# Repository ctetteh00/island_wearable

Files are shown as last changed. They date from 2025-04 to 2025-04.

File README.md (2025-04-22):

# 🌡️ Heat Risk Monitoring System

A dual-device system for real-time, personalized heat stress monitoring. Combines ESP32-based wearable and stationary nodes with a Firebase-connected dashboard to calculate the Modified Physiological Strain Index (mPSI), Heat Index, and a user-specific risk score.

## 🚀 Project Structure

- **Stationary Device**: Measures ambient temperature and humidity, broadcasts data via ESP-NOW.
- **Wearable Device**: Receives strongest signal, calculates skin temperature, uploads all data to Firebase.
- **Web Dashboard**: Real-time interface for monitoring risk levels and metrics.

---

## Repository Structure
/island_wearable/
├── firmware/
│   ├── wearable.ino         # Wearable ESP32 firmware
│   ├── stationary.ino       # Stationary ESP32 firmware
│   └── secrets.h            # Credentials (use from .env)
├── public/
│   ├── index.html           # Web UI
│   ├── app.js               # Logic & Firebase JS SDK
├── docs/
│   ├── 462_island_wearable_2.zip
    ├── wearable.kicad_pcb
    ├── wearable.kicad_pro
    ├── wearable.kicad_sch 
    ├── wearable_circuit_schematic.png
    ├── wearable_pcb_schematic.png
│   └── stationary_schematic.png
├── .env                     # Environment variables
├── setup_dependencies.sh # Library Dependencies for Arduino
├── README.md

## 📦 Hardware Components

### Wearable Device

| Component | Part Number | Description |
|---|---|---|
| Microcontroller | Arduino Nano ESP32 | Wi-Fi + ESP-NOW |
| Temperature Sensor  | TMP236 | Skin temperature measurement |
| Charging Module | Adafruit PowerBoost 1000C | LiPo charging circuit |
| Battery | LP103454 | 3.7V 1000mAh LiPo |
| Strap & Enclosure | Chest band + PLA case  | Wearability and housing |

### Stationary Device

| Component | Part Number | Description |
|---|---|---|
| Microcontroller | Arduino Nano ESP32 | ESP-NOW broadcaster |
| Sensor | DHT22 | Temp + Humidity measurement |
| Power | 9V Battery + Switch | Portable outdoor deployment |
| Case | Acrylic Enclosure | Ventilated weather housing |

---

## 🧠 Features

- ESP-NOW peer-to-peer communication
- RSSI-based device proximity selection
- mPSI calculation with exponential calibration
- Firebase-hosted real-time database
- Personalized scoring with comorbidities, sleep, and medications
- Dynamic UI with recommendations and color-coded feedback

---

## 🌐 Firebase Setup Instructions

1. **Create a Firebase Project**
   - Go to [Firebase Console](https://console.firebase.google.com/)
   - Click **Add Project** → Give it a name → Continue
   - Disable Google Analytics (optional)

2. **Add Realtime Database**
   - Navigate to `Build > Realtime Database`
   - Create a new database in test mode (can secure later)

3. **Set Up Web App**
   - Click **</>** to register a new Web App in Firebase
   - Save the API Key and Database URL (add to `.env`)

4. **Enable Authentication (Optional)**
   - Go to `Authentication > Sign-in method`
   - Enable "Email/Password" or other methods

---

## 🔒 Environment Configuration

Add a `.env` file in the root of your repo:

```env
# Firebase Credentials
FIREBASE_API_KEY=your_api_key_here
FIREBASE_DATABASE_URL=https://your-database-name.firebaseio.com

# WiFi Access
WIFI_SSID="YourNetwork"
WIFI_PASSWORD="YourPassword"

# Optional
WIFI_CHANNEL=1

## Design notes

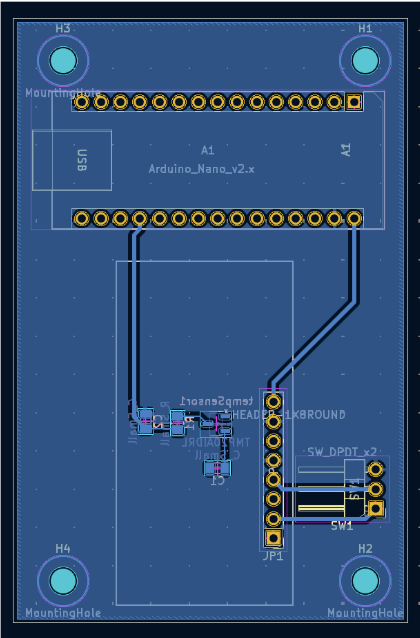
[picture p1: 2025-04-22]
docs/wearable_pcb_schematic.png

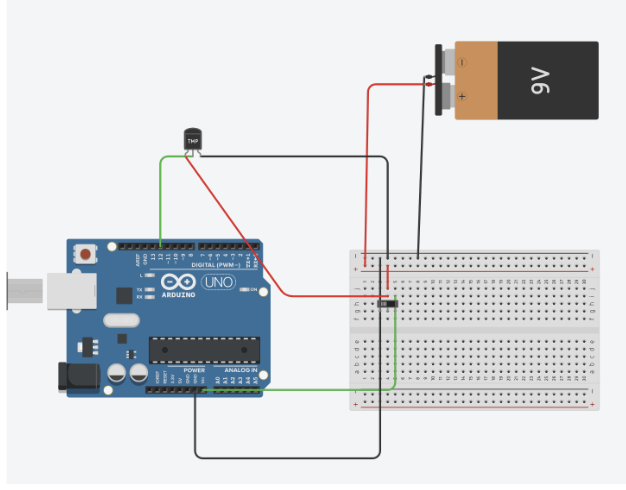
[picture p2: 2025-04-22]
docs/stationary_schematic.png

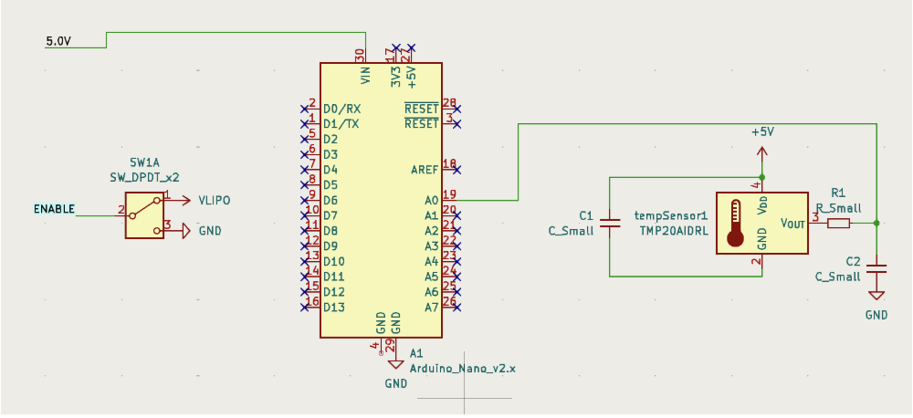
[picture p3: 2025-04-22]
docs/wearable_circuit_schematic.png

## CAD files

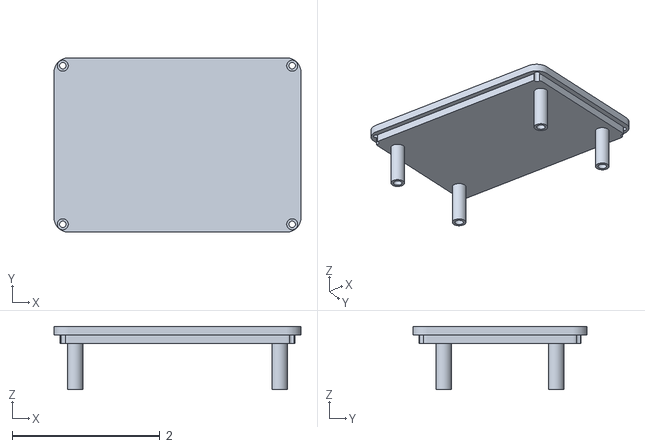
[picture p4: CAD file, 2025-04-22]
stl/Wearable V3 - 2.stl
3.35 x 2.36 x 0.859

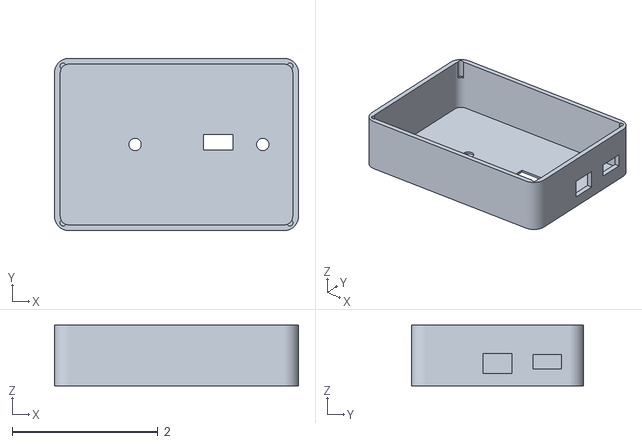
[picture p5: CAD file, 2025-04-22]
stl/Wearable V3-1.stl
3.35 x 2.36 x 0.831

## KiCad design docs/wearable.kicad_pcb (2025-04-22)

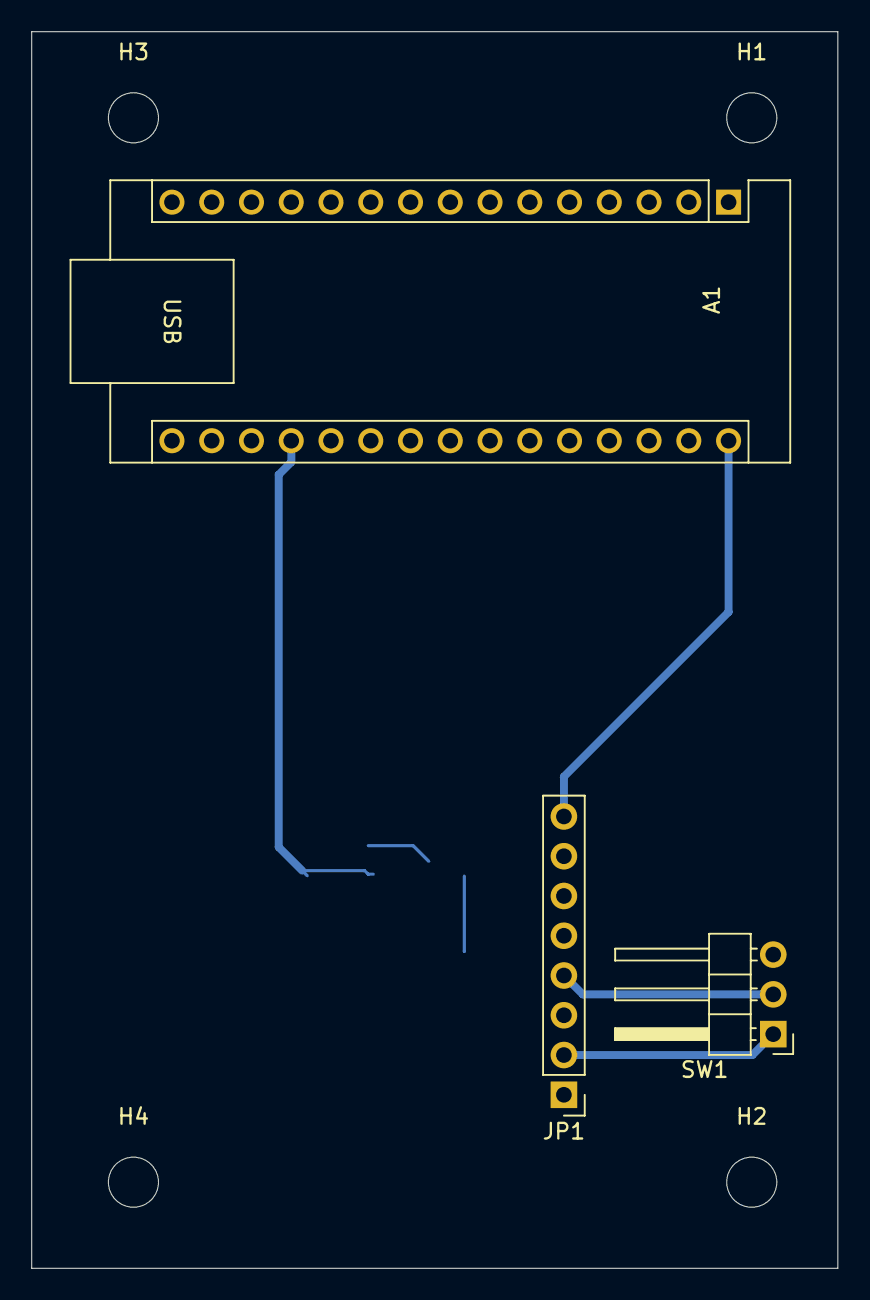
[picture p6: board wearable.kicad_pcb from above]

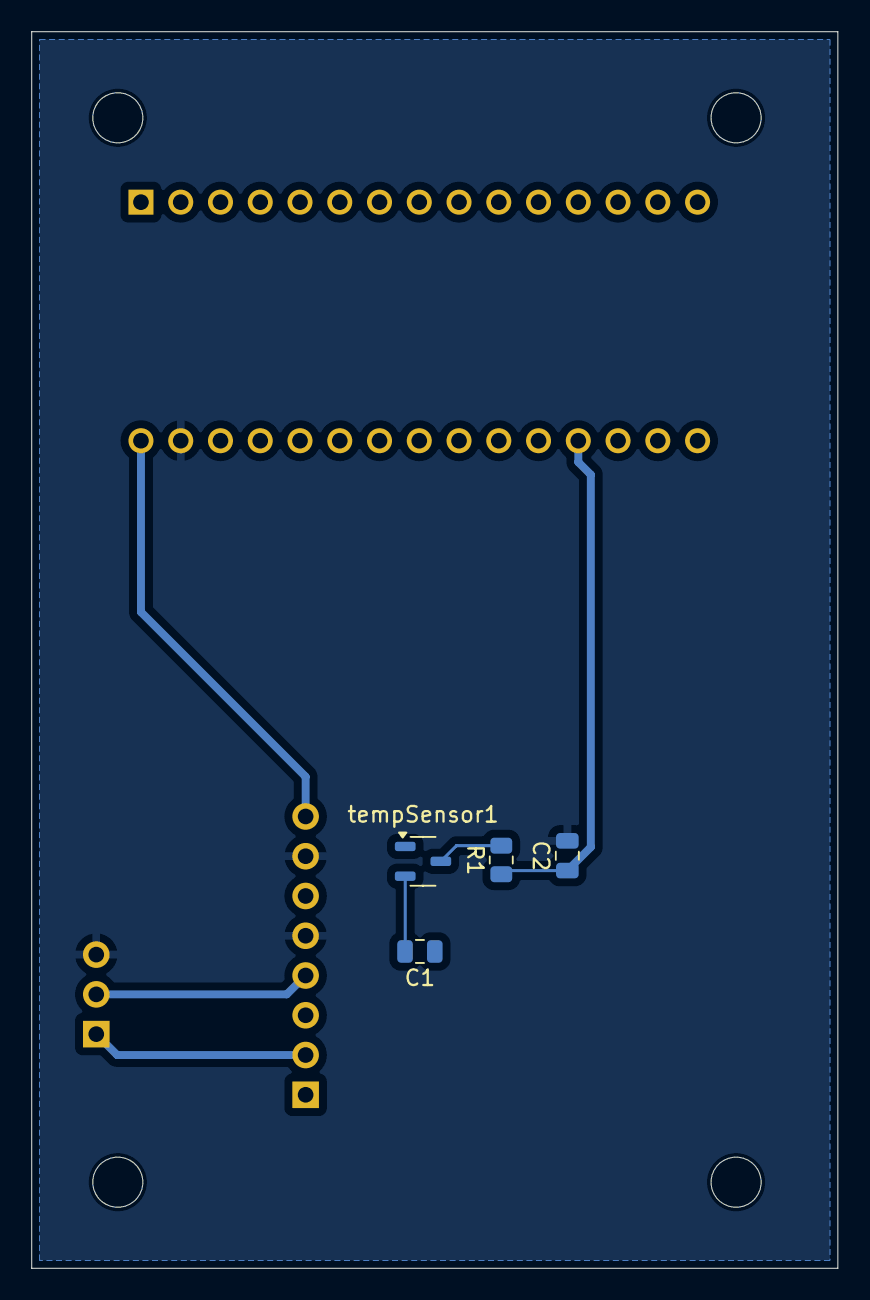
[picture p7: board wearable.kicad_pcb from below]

Board: 2 copper layers, 51.5 x 79.0 mm, 11 parts (4 on the bottom side), 7 nets.

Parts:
A1: Arduino_Nano_v2.x; Arduino_Nano
C1, C2: C_Small; C_0805_2012Metric
H1, H2, H3, H4: MountingHole; MountingHole_3.2mm_M3
JP1: HEADER-1X8ROUND; PinHeader_1x08_P2.54mm_Vertical
R1: R_Small; R_0805_2012Metric
SW1: SW_DPDT_x2; PinHeader_1x03_P2.54mm_Horizontal
tempSensor1: TMP20AIDRL; SOT-23-3

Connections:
5.0V: A1.30 (VIN), JP1.8
/ENABLE: JP1.4, SW1.2 (B)
GND: A1.29 (GND), C2.2, JP1.5, JP1.7, SW1.3 (C)
unnamed: A1.19 (A0), C2.1, R1.1
unnamed: C1.2, tempSensor1.2 (GND)
unnamed: R1.2, tempSensor1.3 (V_{OUT})
VLIPO: JP1.2, SW1.1 (A)

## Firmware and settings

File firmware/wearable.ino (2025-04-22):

// ----------------------------------------
// Heat Risk Monitoring - Wearable Node
// ESP32 Wearable Node receives ESP-NOW data and uploads to Firebase
// ----------------------------------------

#include <Arduino.h>
#include <WiFi.h>
#include <Firebase_ESP_Client.h>
#include <esp_now.h>
#include <esp_wifi.h>
#include <vector>
#include <algorithm>
#include "secrets.h"

// Firebase Helper Includes
#include "addons/TokenHelper.h"
#include "addons/RTDBHelper.h"

// Firebase objects
FirebaseData fbdo;
FirebaseAuth auth;
FirebaseConfig config;
FirebaseJson json;

// Firebase data paths
const char* tempSPath = "/skintemp";
const char* tempAPath = "/ambtemp";
const char* humPath   = "/humidity";
const char* parentPath = "sensor_data";

// Timing
unsigned long sendDataPrevMillis = 0;
const unsigned long sensorTimeout = 10000;
bool signupOK = false;

// -------------------------------
// ESP-NOW Data Structure
// -------------------------------
typedef struct struct_sensor_data {
  uint8_t macAddr[6];
  float skin_temperature;
  float ambient_temperature;
  float humidity;
} sensor_data;

typedef struct received_data_t {
  uint8_t macAddr[6];
  float skin_temperature;
  float ambient_temperature;
  float humidity;
  int8_t rssi;
  unsigned long lastSeen;
} received_data_t;

std::vector<received_data_t> nearbySensors;

// -------------------------------
// Temperature Sensor Setup
// -------------------------------
const int TempPin = 18; // Analog pin connected to TMP236 white wire
const int BUFFER_SIZE = 6;
float temp[BUFFER_SIZE];
int count = 0;
float Vout = 0;

// -------------------------------
// Utility Function: Check MAC Equality
// -------------------------------
bool isSameMac(const uint8_t *addr1, const uint8_t *addr2) {
  return memcmp(addr1, addr2, 6) == 0;
}

// -------------------------------
// ESP-NOW Receive Callback
// -------------------------------
void OnDataRecv(const esp_now_recv_info_t *recv_info, const uint8_t *incomingData, int len) {
  Serial.println("ESP-NOW data received!");
  const uint8_t *peer_addr = recv_info->src_addr;

  if (len == sizeof(sensor_data)) {
    sensor_data receivedTempData;
    memcpy(&receivedTempData, incomingData, sizeof(receivedTempData));
    int8_t rssi = recv_info->rx_ctrl->rssi;

    bool found = false;
    for (auto &sensor : nearbySensors) {
      if (isSameMac(sensor.macAddr, peer_addr)) {
        sensor.skin_temperature = getSkinTemp();
        sensor.ambient_temperature = receivedTempData.ambient_temperature;
        sensor.humidity = receivedTempData.humidity;
        sensor.rssi = rssi;
        sensor.lastSeen = millis();
        found = true;
        break;
      }
    }

    if (!found) {
      received_data_t newSensor;
      memcpy(newSensor.macAddr, peer_addr, 6);
      newSensor.skin_temperature = getSkinTemp();
      newSensor.ambient_temperature = receivedTempData.ambient_temperature;
      newSensor.humidity = receivedTempData.humidity;
      newSensor.rssi = rssi;
      newSensor.lastSeen = millis();
      nearbySensors.push_back(newSensor);
      Serial.print("New sensor discovered with MAC: ");
      for (int i = 0; i < 6; i++) Serial.printf("%02X:", peer_addr[i]);
      Serial.println();
    }

    Serial.printf("Ambient Temp: %.2f°F, RSSI: %d\n", receivedTempData.ambient_temperature, rssi);
  } else {
    Serial.println("ESP-NOW data length mismatch!");
  }
}

// -------------------------------
// Utility Function: Find Nearest Sensor
// -------------------------------
received_data_t* findNearestSensor() {
  if (nearbySensors.empty()) return nullptr;
  received_data_t* nearest = &nearbySensors[0];
  for (size_t i = 1; i < nearbySensors.size(); ++i) {
    if (nearbySensors[i].rssi > nearest->rssi) {
      nearest = &nearbySensors[i];
    }
  }
  return nearest;
}

// -------------------------------
// Setup Function
// -------------------------------
void setup() {
  Serial.begin(115200);
  analogReadResolution(10);
  pinMode(TempPin, INPUT);

  WiFi.mode(WIFI_STA);
  Serial.println("Wearable MAC Address: " + WiFi.macAddress());

  esp_wifi_set_channel(1, WIFI_SECOND_CHAN_NONE);

  if (esp_now_init() == ESP_OK) {
    Serial.println("ESP-NOW initialized");
    esp_now_register_recv_cb(OnDataRecv);
  } else {
    Serial.println("ESP-NOW init failed");
    return;
  }

  // Wi-Fi for Firebase (use empty password for DukeOpen)
  WiFi.begin(WIFI_SSID, "", 1);
  Serial.print("Connecting to Wi-Fi");
  while (WiFi.status() != WL_CONNECTED) {
    Serial.print(".");
    delay(300);
  }
  Serial.println("Connected to WiFi");

  // Firebase setup
  config.api_key = API_KEY;
  config.database_url = DATABASE_URL;
  config.token_status_callback = tokenStatusCallback;

  if (Firebase.signUp(&config, &auth, "", "")) {
    Serial.println("Firebase sign-up OK");
    signupOK = true;
  } else {
    Serial.printf("Firebase sign-up failed: %s\n", config.signer.signupError.message.c_str());
  }

  Firebase.begin(&config, &auth);
  Firebase.reconnectWiFi(true);
}

// -------------------------------
// Measure Skin Temperature
// -------------------------------
float getSkinTemp() {
  Vout = (((float)analogRead(TempPin) * 3.3) / 4095.0) * 1000; // Convert to mV
  float celsiusExpCal = 7.3975 * exp(0.0014 * Vout);
  float celsiusPolyCal = 0.00005 * Vout * Vout + 0.0037 * Vout + 6.09;
  float celsiusAvg = ((celsiusExpCal + celsiusPolyCal) / 2) + 12;
  Serial.printf("Calculated Skin Temp: %.2f °C\n", celsiusAvg);
  return celsiusAvg;
}

// -------------------------------
// Main Loop
// -------------------------------
void loop() {
  // Remove sensors not heard from in a while
  nearbySensors.erase(std::remove_if(nearbySensors.begin(), nearbySensors.end(),
    [](const received_data_t& s) { return (millis() - s.lastSeen > sensorTimeout); }),
    nearbySensors.end());

  received_data_t* nearestSensorPtr = findNearestSensor();

  if (signupOK && nearestSensorPtr != nullptr && (millis() - sendDataPrevMillis > 15000)) {
    sendDataPrevMillis = millis();

    Serial.println("Uploading to Firebase from nearest sensor:");
    for (int i = 0; i < 6; i++) Serial.printf("%02X:", nearestSensorPtr->macAddr[i]);
    Serial.println();
    Serial.printf("Skin Temp: %.2f °C\n", nearestSensorPtr->skin_temperature);
    Serial.printf("Ambient Temp: %.2f °F\n", nearestSensorPtr->ambient_temperature);
    Serial.printf("Humidity: %.2f %%\n", nearestSensorPtr->humidity);

    // Prepare Firebase JSON payload
    json.set(tempSPath, String(nearestSensorPtr->skin_temperature, 2));
    json.set(tempAPath, String(nearestSensorPtr->ambient_temperature, 2));
    json.set(humPath, String(nearestSensorPtr->humidity, 2));

    // Upload to Firebase
    if (Firebase.RTDB.setJSON(&fbdo, parentPath, &json)) {
      Serial.println("Firebase upload successful");
    } else {
      Serial.printf("Firebase error: %s\n", fbdo.errorReason().c_str());
    }
  }

  delay(2000); // Small delay between checks
}

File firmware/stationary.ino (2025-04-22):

// ----------------------------------------
// Heat Risk Monitoring - Stationary Node
// ESP32 Stationary Node sends ambient temp & humidity to Wearable Node via ESP-NOW
// ----------------------------------------

#include <WiFi.h>
#include <esp_now.h>
#include <esp_wifi.h>  // Required to retrieve MAC address
#include "DHT.h"       // DHT Sensor Library

// --- DHT Sensor Configuration ---
#define DHTPIN D12           // DHT22 data pin
#define DHTTYPE DHT22        // Define sensor type
DHT dht(DHTPIN, DHTTYPE);    // Initialize DHT sensor

// --- Data Structure to Send ---
typedef struct struct_sensor_data {
  uint8_t macAddr[6];             // Sender MAC Address
  float skin_temperature;         // Placeholder for skin temp (not used in this node)
  float ambient_temperature;      // Ambient temperature from DHT
  float humidity;                 // Relative humidity from DHT
} sensor_data;

sensor_data myData;               // Instance of data struct

// MAC address of the Wearable Node (Receiver)
uint8_t receiverMacAddress[] = {0xEC, 0xDA, 0x3B, 0x61, 0x93, 0xA4};

// --- Callback on Send Completion ---
void OnDataSent(const uint8_t *mac_addr, esp_now_send_status_t status) {
  Serial.print("Last Packet Send Status to: ");
  for (int i = 0; i < 6; i++) Serial.printf("%02X:", mac_addr[i]);
  Serial.print(" Status: ");
  Serial.println(status == ESP_NOW_SEND_SUCCESS ? "Delivery Success" : "Delivery Fail");
}

void setup() {
  Serial.begin(115200);
  dht.begin();  // Start DHT sensor
  Serial.println("Stationary ESP32 (Sender)");

  // --- WiFi Setup for ESP-NOW ---
  WiFi.mode(WIFI_STA);  // Set ESP32 to station mode
  esp_wifi_set_channel(1, WIFI_SECOND_CHAN_NONE);  // Lock channel to 1
  Serial.print("Current WiFi channel: ");
  Serial.println(WiFi.channel());

  // --- ESP-NOW Initialization ---
  if (esp_now_init() != ESP_OK) {
    Serial.println("Error initializing ESP-NOW");
    return;
  }

  // Register callback to check send status
  esp_now_register_send_cb(OnDataSent);

  // Get this node's MAC address and save to packet
  esp_wifi_get_mac(WIFI_IF_STA, myData.macAddr);
  Serial.print("Stationary Node MAC Address: ");
  Serial.println(WiFi.macAddress());
}

void loop() {
  // Read data from DHT sensor
  myData.skin_temperature = 0.0f;  // Not applicable for this device
  myData.ambient_temperature = dht.readTemperature(true);  // true = Fahrenheit
  myData.humidity = dht.readHumidity();

  // --- Peer Configuration ---
  esp_now_peer_info_t peerInfo;
  memset(&peerInfo, 0, sizeof(esp_now_peer_info_t));
  memcpy(peerInfo.peer_addr, receiverMacAddress, 6);  // Set receiver MAC
  peerInfo.channel = 1;       // Must match both sender & receiver
  peerInfo.encrypt = false;   // Encryption not used in this version

  // Add peer if not already known
  if (!esp_now_is_peer_exist(peerInfo.peer_addr)) {
    esp_err_t addPeerResult = esp_now_add_peer(&peerInfo);
    if (addPeerResult != ESP_OK) {
      Serial.print("Failed to add peer: ");
      Serial.println(esp_err_to_name(addPeerResult));
      delay(2000);
      return;
    } else {
      Serial.println("Peer added successfully");
    }
  }

  // --- Send Data Packet ---
  esp_err_t result = esp_now_send(peerInfo.peer_addr, (uint8_t *) &myData, sizeof(myData));
  if (result == ESP_OK) {
    Serial.println("Data Sent:");
    Serial.printf("Ambient Temp: %.2f °F\n", myData.ambient_temperature);
    Serial.printf("Humidity: %.2f %%\n", myData.humidity);
  } else {
    Serial.print("Error sending data: ");
    Serial.println(esp_err_to_name(result));
  }

  delay(10000);  // Send every 10 seconds
}

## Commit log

2025-04-22 arduino files
2025-04-22 pushing all files up
    [Wearable V3 - 2.stl, Wearable V3-1.stl, wearable.kicad_pcb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]
